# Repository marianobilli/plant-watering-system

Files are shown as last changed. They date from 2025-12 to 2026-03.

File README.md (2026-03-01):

# DIY Plant Watering System

> Automated single-plant watering on Arduino UNO R4 WiFi — dry-cycle logic, incremental dosing, 14-bit ADC, EEPROM logging, and a full LCD menu with calibration wizard.

[]()
[]()
[]()


---

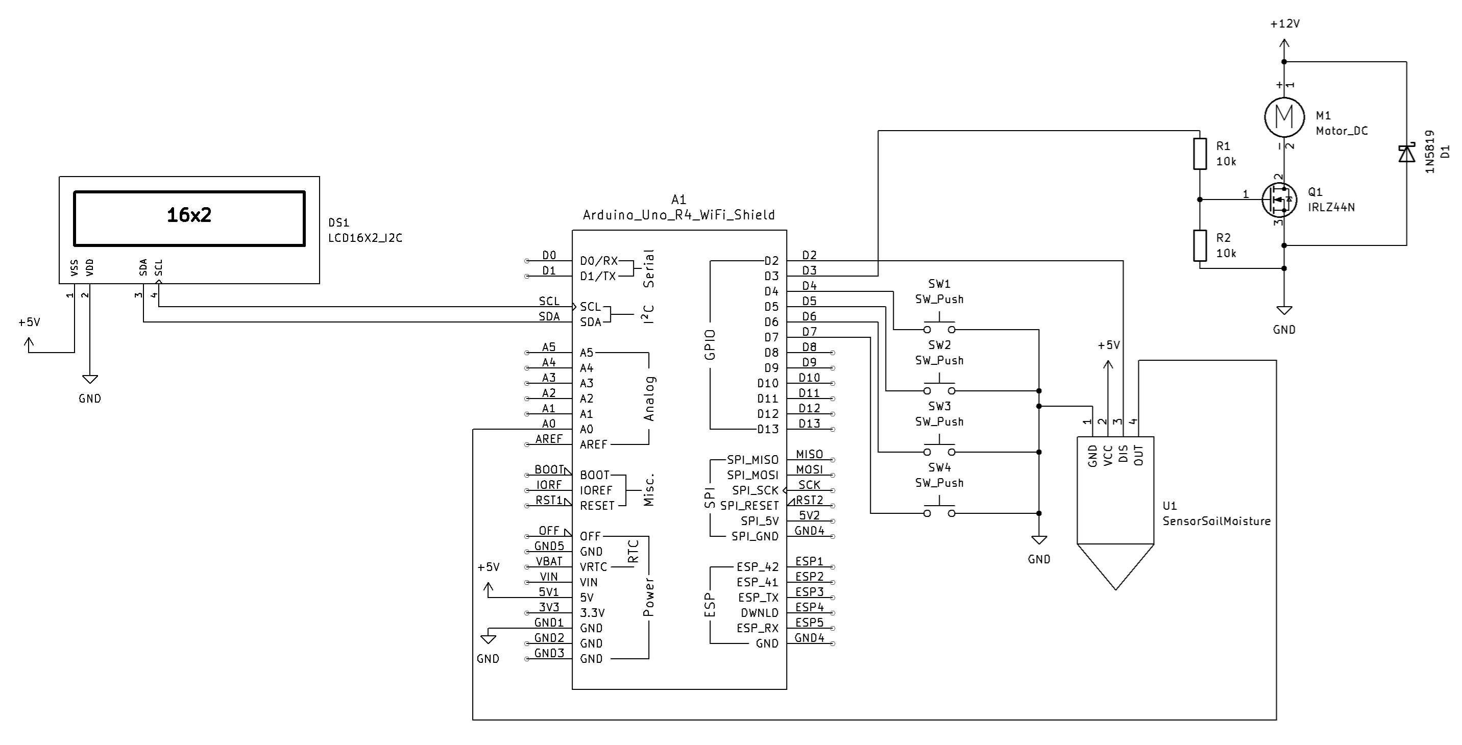
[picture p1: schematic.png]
Schematic


---

## How It Works

**Dry cycle** — Moisture is logged every 15 minutes. Auto-watering fires only after **two consecutive readings** below the minimum threshold (default 55%), avoiding false triggers from sensor noise.

**Incremental watering** — On the first trigger, the pump delivers an initial 50 mL dose, then waits 15 minutes for capillary absorption before re-reading. If moisture is still below the target (75%), additional 10 mL increments are delivered with 1-minute soak times between each. If moisture fails to rise after pumping, the system halts to prevent flooding.

---

## Key Design Decisions

| Decision | What | Why |
|---|---|---|
| Capacitive sensor | Cytron MCP6004-based | No electrolytic corrosion; lasts 1–2+ years vs weeks for resistive |
| DIS pin control | Sensor powered via D2 | Only energized during readings; extends sensor life, reduces parasitic current |
| 14-bit ADC | `analogReadResolution(14)` | 16 384 steps vs 1 024; far better moisture resolution |
| Median sampling | 10 samples, bubble sort | Rejects outliers; more stable than averaging alone |
| Peristaltic pump | 12V S-3Z type | Safe to run dry, precise dosing, no gravity siphoning |
| MOSFET switch | IRLZ44N logic-level | Silent, fast, no coil current; flyback diode (1N5819) on pump |
| Incremental watering | 50 mL initial + 10 mL steps | Prevents overwatering; allows soil absorption between doses |
| Soak times | 15 min initial / 1 min increment | Waits for capillary propagation before re-reading moisture |
| Dry-reading debounce | 2 consecutive low readings | Avoids watering on transient sensor noise |
| EEPROM circular log | 246 entries × 4 bytes | ~2.7 days of history at 15-min intervals; survives reboots |
| Backlight auto-sleep | 1 min timeout | Reduces LCD wear; wakes on any button press |

---

## Documentation

| File | Contents |
|---|---|
| [BOM.md](BOM.md) | Parts list with Allegro.pl / Botland.pl links and cost (~500 PLN) |
| [WATERING_LOGIC.md](WATERING_LOGIC.md) | Dry-cycle and incremental watering algorithm explained |
| [MENU_DESIGN.md](MENU_DESIGN.md) | 16×2 LCD menu structure, screen layouts, EEPROM map, state machine |
| [LESSONS_DEEP_RESEARCH.md](LESSONS_DEEP_RESEARCH.md) | Research findings from 50+ community projects |
| [watering/](watering/) | Firmware (v1.1), build guide, changelog |

---

## Repository Structure

```
plant-watering-system/
├── README.md
├── BOM.md
├── WATERING_LOGIC.md
├── MENU_DESIGN.md
├── LESSONS_DEEP_RESEARCH.md
└── watering/
    ├── README.md           # Build and upload guide
    ├── build.md            # Wiring, pin assignments, MOSFET circuit
    ├── BOM_WATERING.md     # Watering-system-specific BOM
    ├── CHANGELOG.md        # Firmware version history
    └── src/
        └── plant_watering/
            └── plant_watering.ino
```

---

## License

MIT

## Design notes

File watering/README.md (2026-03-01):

# Plant Watering System - Phase 2 (Auto-Watering Firmware)

Version 1.0 — First full auto-watering implementation combining reliable sensor reading with automatic watering logic.

## Overview

Phase 2 transforms the monitor-only firmware (Phase 1) into a **fully automatic plant watering system**. The firmware reads soil moisture via a 14-bit ADC sensor (with DIS pin control for power efficiency), and automatically activates a 12V peristaltic pump when soil moisture drops below a configurable threshold.

**Key improvements over POC:**
- ✅ **Correct 14-bit ADC handling** — includes `analogReadResolution(14)` to prevent ~16× calibration error
- ✅ **DIS pin sensor control** — extends sensor lifespan vs. VCC-cycling
- ✅ **Configurable median sampling** — robustness + flexibility (adjust sample count, delays)
- ✅ **EEPROM persistence** — all watering and sensor parameters saved across power cycles
- ✅ **Circular logging** — ~2.7 days of moisture history in 2KB EEPROM (~400 entries @ 15-min intervals)
- ✅ **Automatic failsafe** — stops watering if moisture doesn't increase (pump/sensor fault detection)

## Hardware Requirements

### Arduino & Sensor
- **1× Arduino UNO R4 WiFi** (or UNO R3 with WiFi shield if needed)
- **1× Capacitive Soil Moisture Sensor** with DIS pin (e.g., DF-Robot SEN0193 or similar)
- **1× 16x2 I2C LCD Display** (address 0x27 or 0x3F)
- **4× Pushbuttons** (UP/DOWN/SELECT/BACK navigation)

### Pump & Power Electronics
- **1× 12V Peristaltic Pump** (e.g., S-3Z model, ~1.67 mL/s flow rate)
- **1× IRLZ44N N-Channel Logic-Level MOSFET** (gate driver for pump)
- **1× 1N5819 Schottky Diode** (flyback protection on pump coil)
- **2× 10kΩ Resistors** (MOSFET gate current limit + pull-down)
- **1× 12V 2A Power Supply** (for pump + tube + connectors)
- **Dual USB + 12V Power** (Arduino from USB, pump from 12V) or single 12V supply with buck converter

## Pin Assignments

| Pin | Function | Purpose |
|-----|---|---|
| A0 | Soil Moisture Sensor ADC | Analog input (14-bit, 0-16383) |
| D2 | Sensor DIS Pin | Disable pin control (HIGH=sleep, LOW=active) |
| D3 | Pump MOSFET Gate | MOSFET control signal (HIGH=pump ON) |
| D4 | Button UP | Navigation up |
| D5 | Button DOWN | Navigation down |
| D6 | Button SELECT | Menu select / confirm |
| D7 | Button BACK | Menu back / cancel |
| SDA (A4) | LCD I2C Data | I2C communication |
| SCL (A5) | LCD I2C Clock | I2C communication |

## Firmware Features

### Operating Mode: Auto-Watering (Default)
- Continuous monitoring with configurable check intervals (1-24 hours)
- Dry cycle logic: only waters when soil moisture ≤ `minThreshold`
- Incremental watering: pumps configurable water amounts, waits for capillary absorption, checks moisture
- Automatic failsafe: stops if moisture doesn't increase (pump fault, sensor error, etc.)
- Soak time: waits N minutes between increments for moisture to propagate through soil

### Configuration (EEPROM-Persisted)
**Watering Parameters:**
- `targetHumidity` — Stop watering when moisture reaches this % (default: 75%)
- `minThreshold` — Start watering when moisture drops below this % (default: 55%)
- `waterAmountInitial` — Initial pump amount in mL (default: 50 mL)
- `waterAmountIncrement` — Each subsequent pump amount in mL (default: 10 mL)
- `checkInterval` — Hours between dry-cycle checks (default: 6 hours)
- `soakTime` — Minutes to wait after initial pump (default: 5 minutes)
- `soakTimeIncrement` — Minutes to wait between increments (default: 1 minute)
- `pumpRate` — mL/s calibrated from pump hardware (default: 1.67 mL/s)

**Sensor Parameters:**
- `sensorDry` — 14-bit ADC value in air (default: 11850, user-calibrated)
- `sensorWet` — 14-bit ADC value in water (default: 7700 @ 60cm depth)
- `sensorWarmup` — Sensor stabilization delay in ms (default: 1000ms)
- `numMeasurements` — Sample count for median (default: 10)
- `measurementDelay` — ms between samples (default: 100ms)

**Display:**
- `backlightTimeout` — LCD auto-sleep delay in minutes (default: 1 minute)

### Menu Structure
```
STATUS SCREEN
└─ [Select] → MAIN MENU
   ├─ Settings
   │  ├─ Target % (watering stop threshold)
   │  ├─ Min Threshold (watering start trigger)
   │  ├─ Water Amount (mL per increment)
   │  ├─ Check Interval (hours)
   │  ├─ Soak Time (minutes)
   │  ├─ Sensor Warmup (ms)
   │  ├─ Num Samples (count)
   │  └─ LCD Sleep (minutes)
   ├─ Calibrate
   │  ├─ Sensor (air → water or depth lookup)
   │  └─ Pump (measure actual mL output)
   ├─ Manual Water (trigger one cycle now)
   ├─ Download Log (Serial CSV dump)
   └─ Reset Defaults
```

### Data Logging
- **Circular EEPROM buffer:** ~400 entries × ~4 bytes = 2KB in EEPROM
- **Logging interval:** Configurable (default: 15 minutes)
- **Duration:** ~2.7 days of continuous monitoring at 15-min intervals before buffer wraps
- **CSV download:** Connect USB Serial Monitor @ 115200 baud, select "Download Log" → see CSV lines:
  ```
  1665.3,78,8567,0
  1680.5,79,8545,0
  ...
  ```
  (Time[hours], Moisture[%], Raw ADC, Flags)

## Building & Setup

See `build.md` for:
- Step-by-step wiring with corrected Arduino D2/D3 pins
- MOSFET circuit assembly (breadboard diagram)
- Sensor DIS pin vs. VCC-cycling explanation
- Power supply connections (dual USB+12V or single 12V)
- Safety checklist

## Calibration

### Sensor Calibration
1. Insert sensor in **air** (dry) — records ADC value (default: 11850)
2. Insert sensor in **water** at known depth (60cm recommended) — records ADC value (default: 7700)
3. Firmware maps [dry ADC → 0%, wet ADC → 100%]

See **monitor v1.5 sensor data** (from Phase 1): observed "healthy" moist soil reads 77–79% (ADC ~8567–8617)

### Pump Calibration
1. Run **Pump Calibration** wizard → pump runs for timed duration
2. Measure water collected in graduated cylinder (mL)
3. Enter mL — firmware calculates flow rate (mL/s)
4. Verifies pump is functional and rate is consistent with configuration

## Default Threshold Recommendation

Based on **monitor/data/data.csv** (Phase 1 real data):
- Healthy moist soil: 77–79% (ADC 8567–8617) over 8+ hours
- **Default:** `minThreshold = 55%` (triggers watering) → `targetHumidity = 75%` (stops when sufficiently moist)
- This provides earlier watering triggers for more frequent soil hydration, stopping at a lower moisture level

## Verification Steps

1. **Wiring test (no firmware):**
   - Connect MOSFET circuit, apply 12V
   - Briefly connect Arduino D3 to 5V → pump should spin

2. **Sensor test:**
   - Upload firmware
   - Open Serial Monitor @ 115200 baud
   - Verify ADC reads 10000–12000 in air (not 500–900, which indicates missing `analogReadResolution(14)`)

3. **Pump calibration:**
   - Run calibration wizard
   - Measure actual water output with graduated cylinder
   - Enter mL, firmware calculates rate

4. **Sensor calibration:**
   - Air (dry value) → water (wet value)
   - Verify % reads 0% in air, 100% in water

5. **Threshold test:**
   - Temporarily set `minThreshold = 70%`
   - Observe auto-watering triggers as expected
   - Reset to 40% after testing

6. **Log download:**
   - After a few watering cycles, open Serial Monitor
   - Select "Download Log" → observe CSV lines with moisture history

## Version History

See `CHANGELOG.md`

## Support

- **Wiring issues?** See `build.md` or `../WIRING_POC.md`
- **Sensor not reading?** Run Sensor Calibration wizard (Settings → Calibrate)
- **Pump not working?** Run Pump Calibration wizard to verify flow rate
- **Arduino won't upload?** Check USB cable, verify CH340 drivers (if using CH340 UART)

---

*Phase 2 v1.0 — Auto-Watering Firmware*
*Based on Phase 1 monitor v1.5 (sensor reading) + POC (watering logic)*
*Combines proven sensor code with enhanced watering reliability*

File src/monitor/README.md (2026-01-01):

# Soil Humidity Monitor - User Guide

**2-Week EEPROM Data Logger for Plant Moisture Analysis**

A simplified monitoring-only variant designed to help you understand your plant's natural watering cycles before implementing automatic irrigation. Logs 1,344 measurements over 14 days to Arduino UNO R4 WiFi's 8KB EEPROM.

---

## Quick Start (5-Minute Setup)

1. **Waterproof sensor** (2 coats clear nail polish, dry 24h)
2. **Wire components** per schematic (20 connections)
3. **Upload firmware** via Arduino IDE (30 seconds)
4. **Calibrate sensor** (Main Menu → Calibrate → air + water)
5. **Insert in soil** → Auto-logging begins!

**After 2 weeks:** Download CSV via Serial Monitor (115200 baud) → Analyze in Excel/Python

---

## Table of Contents

1. [Hardware Assembly](#hardware-assembly)
2. [Firmware Upload](#firmware-upload)
3. [First-Time Setup](#first-time-setup)
4. [Operating the System](#operating-the-system)
5. [CSV Download Instructions](#csv-download-instructions)
6. [Data Analysis Workflow](#data-analysis-workflow)
7. [Troubleshooting](#troubleshooting)
8. [Technical Specifications](#technical-specifications)

---

## Hardware Assembly

### Components Required

See [`BOM_MONITOR.md`](BOM_MONITOR.md) for complete parts list (~$42 USD).

**Core items:**
- Arduino UNO R4 WiFi
- Capacitive soil moisture sensor
- 16×2 I2C LCD display
- 4× tactile push buttons
- Breadboard + jumper wires
- USB-C cable (data + power)

### Wiring Diagram

**Pin Connections:**

| Component | Pin | Arduino Pin | Notes |
|---|-----|---|---|
| **Soil Sensor** | VCC | D2 | GPIO power control (critical!) |
| | AOUT | A0 | 14-bit ADC input |
| | GND | GND | Common ground |
| **16×2 LCD** | VCC | 5V | I2C module |
| | GND | GND | |
| | SDA | SDA (A4) | I2C data |
| | SCL | SCL (A5) | I2C clock |
| **Button UP** | Pin 1 | D4 | Internal pullup enabled |
| | Pin 2 | GND | Active LOW |
| **Button DOWN** | Pin 1 | D5 | Internal pullup |
| | Pin 2 | GND | |
| **Button SELECT** | Pin 1 | D6 | Internal pullup |
| | Pin 2 | GND | |
| **Button BACK** | Pin 1 | D7 | Internal pullup |
| | Pin 2 | GND | |
| **USB Cable** | USB-C | Arduino USB port | Power + Serial data |

**Complete schematic:** See [`soil_humidity_monitor.kicad_sch`](soil_humidity_monitor.kicad_sch)

### Assembly Steps

1. **Prepare Sensor (CRITICAL - do this first!):**
   ```
   1. Apply clear nail polish to sensor PCB (front + back)
   2. Avoid coating the metal probes themselves
   3. Let dry 30 minutes
   4. Apply second coat
   5. Let dry 24 hours before use
   ```
   **Why?** Waterproofing extends sensor life from 3-6 months to 1-2+ years.

2. **Connect LCD:**
   - 5V → LCD VCC
   - GND → LCD GND
   - SDA (A4) → LCD SDA
   - SCL (A5) → LCD SCL

3. **Connect Sensor:**
   - D2 → Sensor VCC (GPIO-powered!)
   - GND → Sensor GND
   - A0 → Sensor AOUT

4. **Connect Buttons:**
   - D4 → Button UP Pin 1, GND → Button UP Pin 2
   - D5 → Button DOWN Pin 1, GND → Button DOWN Pin 2
   - D6 → Button SELECT Pin 1, GND → Button SELECT Pin 2
   - D7 → Button BACK Pin 1, GND → Button BACK Pin 2

5. **Double-Check:**
   - [ ] No shorts between 5V and GND
   - [ ] Sensor powered from D2 (not 5V rail)
   - [ ] LCD I2C connections not swapped
   - [ ] All button pins connected to GND

---

## Firmware Upload

### Prerequisites

1. **Install Arduino IDE** (2.0 or newer)
   - Download: https://www.arduino.cc/en/software

2. **Install Board Support:**
   - Open Arduino IDE
   - Tools → Boards Manager → Search "Arduino UNO R4"
   - Install "Arduino UNO R4 Boards" by Arduino

3. **Install Libraries:**
   - Sketch → Include Library → Manage Libraries
   - Search and install:
     - **LiquidCrystal I2C** by Frank de Brabander (v1.1.2+)
   - Built-in libraries (no install needed): Wire, EEPROM

### Upload Steps

1. **Open Firmware:**
   - File → Open → Navigate to `soil_humidity_monitor.ino`

2. **Configure Board:**
   - Tools → Board → Arduino UNO R4 WiFi
   - Tools → Port → (select your Arduino's COM port)

3. **Upload:**
   - Click Upload button (→) or press Ctrl+U
   - Wait for "Done uploading" message (~30 seconds)

4. **Verify:**
   - LCD should display: "Plant Monitor" and "Initializing..."
   - Status screen should appear with "Moisture: --%" and "Log: 0/1344"

**Troubleshooting Upload Errors:**
- **Port not found:** Install CH340 USB drivers
- **Compilation error:** Check Arduino UNO R4 board support installed
- **Upload timeout:** Press reset button on Arduino, then upload again

---

## First-Time Setup

### 1. Initial Boot

LCD displays:
```
Plant Monitor
Initializing...
```

Then automatically shows **Status Screen**:
```
Moisture: --%
Log:0/1344
```

### 2. Sensor Calibration (REQUIRED)

**Why?** Each sensor has different ADC values for dry/wet conditions. Calibration ensures accurate 0-100% readings.

**Steps:**

1. **Enter Menu:**
   - Press SELECT button (LCD backlight turns on)
   - Display shows: "Main Menu" / "1. Settings"

2. **Navigate to Calibrate:**
   - Press DOWN button twice
   - Display shows: "Main Menu" / "2. Calibrate Sensor"
   - Press SELECT

3. **Dry Calibration:**
   - Display shows: "Hold sensor in AIR" / "Press SELECT"
   - Hold sensor in open air (not touching anything)
   - Wait 2 seconds for stable reading
   - Press SELECT
   - Display shows: "Dry value: XXXX" (e.g., 12400)

4. **Wet Calibration:**
   - Display shows: "Put sensor in WATER" / "Press SELECT"
   - Submerge sensor probes in glass of water (don't submerge entire PCB!)
   - Wait 2 seconds for water to saturate sensor
   - Press SELECT
   - Display shows: "Wet value: XXXX" (e.g., 6000)

5. **Confirmation:**
   - Display shows: "Calibration saved!" / "(values in EEPROM)"
   - Press BACK to return to Main Menu
   - Press BACK again to return to Status Screen

**Calibration values persist through power cycles** - you only need to do this once!

### 3. Adjust Log Interval (Optional)

Default: 15 minutes (optimal for 14-day storage)

**To change:**

1. Main Menu → 1. Settings
2. Press SELECT
3. Display shows: "Log Interval: 15 min"
4. Use UP/DOWN buttons to adjust (1-60 minutes)
5. Press SELECT to save
6. Press BACK to exit

**Storage duration based on interval:**

| Interval | Duration | Use Case |
|---|---|---|
| 10 min | 9.3 days | Fast data collection |
| 15 min | 14.0 days | **Default (optimal)** |
| 30 min | 28.0 days | Long-term trends |
| 60 min | 56.0 days | Extended monitoring |

---

## Operating the System

### Status Screen (Default View)

**What you see:**
```
Moisture: 75%
Log:456/1344
```

**Line 1:** Current soil moisture (0-100%)
- Updates every 2 seconds when backlight is on
- Shows "--%" before first calibration

**Line 2:** Logged entries / total capacity
- Example: "456/1344" = 456 readings stored, 1,344 max
- When full, oldest entries are automatically overwritten (circular buffer)

### Navigation Controls

| Button | Action |
|---|---|
| **UP** | Move up in menu / Increase value |
| **DOWN** | Move down in menu / Decrease value |
| **SELECT** | Enter menu / Confirm action |
| **BACK** | Exit menu / Cancel action |

**Backlight behavior:**
- Turns on when any button pressed
- Stays on for 1 minute
- Auto-sleeps to save power
- Data logging continues in background

### Menu Structure

```
STATUS SCREEN (default view)
│
SELECT → MAIN MENU
         ├── 1. Settings
         │   └── Log Interval (1-60 min)
         ├── 2. Calibrate Sensor
         │   ├── Hold in AIR → Press SELECT
         │   └── Put in WATER → Press SELECT
         ├── 3. Download Data
         │   ├── "Ready to download?" → SELECT to confirm
         │   ├── Progress bar (0-100%)
         │   └── "Download complete!"
         ├── 4. Clear Data
         │   └── "Clear all logs?" → SELECT to confirm
         ├── 5. System Info
         │   ├── "Entries: 456/1344"
         │   ├── "Days: 4.8/14.0"
         │   └── "Firmware: v1.0"
         └── 6. Reset to Defaults
             └── "Reset config?" → SELECT to confirm
```

### Automatic Logging

**How it works:**
- Every 15 minutes (or your configured interval), the system:
  1. Powers on sensor (D2 = HIGH)
  2. Waits 200ms for warmup
  3. Takes 20 ADC readings (averaged to reduce noise)
  4. Powers off sensor (D2 = LOW)
  5. Converts to 0-100% using calibration
  6. Writes 4-byte entry to EEPROM
  7. Updates entry counter

**No user action required** - logging happens automatically in background.

**Entry count updates:**
- Status screen shows current count
- When reaching 1,344 entries (capacity), oldest entries overwrite automatically
- Entry count freezes at 1,344 when buffer is full

---

## CSV Download Instructions

### Method 1: Arduino IDE Serial Monitor (Easiest)

1. **Connect Arduino** via USB cable to computer

2. **Open Serial Monitor:**
   - Arduino IDE → Tools → Serial Monitor
   - Set baud rate: **115200** (bottom-right dropdown)
   - Set line ending: "Newline" or "Both NL & CR"

3. **Start Download on Arduino:**
   - Press SELECT (enter Main Menu)
   - Navigate: DOWN → DOWN → "3. Download Data"
   - Press SELECT
   - Display shows: "Ready to download?" / "SELECT=Yes BACK=No"
   - Press SELECT to confirm

4. **Monitor Progress:**
   - Serial Monitor shows metadata header
   - CSV data rows stream (Entry, Timestamp, Moisture%, etc.)
   - LCD shows progress bar: "Downloading... [####----] 50%"
   - Takes ~30-60 seconds for 1,344 entries

5. **Save CSV File:**
   - When complete, Serial Monitor shows: "# End of data export"
   - Select all text in Serial Monitor (Ctrl+A)
   - Copy (Ctrl+C)
   - Paste into text editor
   - Save as `moisture_data.csv`

### Method 2: Command-Line Serial (Advanced)

**Linux/Mac:**
```bash
# Find Arduino port
ls /dev/tty.* | grep usb

# Start serial capture
screen /dev/tty.usbserial-XXXXXX 115200 > moisture_data.csv

# On Arduino: Main Menu → Download Data → SELECT
# Wait for download to complete
# Stop capture: Ctrl+A, then K, then Y
```

**Windows (PowerShell):**
```powershell
# Open serial port
$port = new-Object System.IO.Ports.SerialPort COM3,115200,None,8,One
$port.Open()

# On Arduino: Main Menu → Download Data → SELECT

# Read data to file
$data = $port.ReadLine()
$data | Out-File -FilePath moisture_data.csv -Append

# Close port when done
$port.Close()
```

### CSV Format

**Example output:**
```csv
# Soil Humidity Monitor Data Export
# Firmware Version: 1.0
# Total Entries: 1234
# Log Interval: 15 minutes
# Sensor Calibration: Dry=12400, Wet=6000
# Buffer Status: NOT_WRAPPED
#
Entry,Timestamp_Hours,Timestamp_Minutes,Moisture_%,Raw_ADC,Flags
1,0.00,0,45,8500,0x00
2,0.25,15,46,8450,0x00
3,0.50,30,47,8400,0x00
...
1234,308.25,18495,52,7800,0x00
```

**Columns:**
- **Entry:** Sequential number (1-1344)
- **Timestamp_Hours:** Hours since monitoring started
- **Timestamp_Minutes:** Total minutes since start
- **Moisture_%:** Calibrated moisture (0-100%)
- **Raw_ADC:** Raw 14-bit ADC value (0-16383)
- **Flags:** Status bits (0x00 = normal, 0x01 = sensor error)

---

## Data Analysis Workflow

### Step 1: Import CSV to Excel

1. Open Excel
2. Data → From Text/CSV
3. Select `moisture_data.csv`
4. Delimiter: Comma
5. Click Load

**Skip comment lines** (lines starting with `#`) or delete them manually.

### Step 2: Create Charts

**Time-Series Plot:**
- X-axis: `Timestamp_Hours` or `Timestamp_Minutes`
- Y-axis: `Moisture_%`
- Chart type: Scatter with smooth lines

**What to look for:**
- **Dry-down rate:** How fast moisture drops naturally
- **Watering events:** Sharp increases (if manually watered)
- **Stabilization level:** Where moisture settles after watering
- **Daily patterns:** Does moisture change with temperature/sunlight?

### Step 3: Calculate Key Metrics

**Natural Dry-Down Rate:**
```
Rate = (Moisture_start - Moisture_end) / Time_hours
Example: (80% - 30%) / 120 hours = 0.42% per hour
```

**Optimal Watering Threshold:**
- Find moisture level where plant shows stress (wilting)
- Water before reaching this point
- Typical range: 10-30% depending on plant species

**Moisture Propagation Time:**
- How long after watering does sensor see moisture increase?
- Typical: 5-15 minutes (depends on soil type, water amount)

### Step 4: Configure Automatic Watering

Use insights to configure POC automatic watering system:

1. **Set Min Threshold:** 5-10% above stress point
   - Example: Plant wilts at 15% → Set `minThreshold = 20%`

2. **Set Target Humidity:** Peak moisture after manual watering
   - Example: Manual watering reaches 75% → Set `targetHumidity = 75%`

3. **Set Soak Time:** Moisture propagation time + buffer
   - Example: Sensor updates in 8 minutes → Set `soakTime = 10 minutes`

4. **Set Check Interval:** 2-3× natural dry-down period
   - Example: Dries from 80% → 30% in 5 days → Set `checkInterval = 12 hours`

**See POC `plant_watering_poc.ino` for automatic watering implementation.**

### Example Analysis (Python)

```python
import pandas as pd
import matplotlib.pyplot as plt

# Load CSV
df = pd.read_csv('moisture_data.csv', comment='#')

# Plot time series
plt.figure(figsize=(12, 6))
plt.plot(df['Timestamp_Hours'], df['Moisture_%'], linewidth=1)
plt.xlabel('Time (hours)')
plt.ylabel('Soil Moisture (%)')
plt.title('2-Week Soil Moisture Monitoring')
plt.grid(True, alpha=0.3)
plt.tight_layout()
plt.savefig('moisture_trend.png', dpi=300)
plt.show()

# Calculate dry-down rate (linear regression)
from scipy.stats import linregress
slope, intercept, r_value, p_value, std_err = linregress(
    df['Timestamp_Hours'], df['Moisture_%']
)
print(f"Dry-down rate: {slope:.3f}% per hour")
print(f"R²: {r_value**2:.3f}")

# Find minimum moisture
min_moisture = df['Moisture_%'].min()
min_timestamp = df.loc[df['Moisture_%'].idxmin(), 'Timestamp_Hours']
print(f"Minimum moisture: {min_moisture}% at {min_timestamp:.1f} hours")
```

---

## Troubleshooting

### Sensor Issues

**Problem:** Moisture reads 0% or 100% constantly
- **Cause:** Sensor not calibrated
- **Fix:** Main Menu → Calibrate Sensor → Follow wizard (air + water)

**Problem:** Moisture fluctuates wildly (e.g., 20% → 80% → 30%)
- **Cause:** Poor electrical contact or sensor corrosion
- **Fix:**
  1. Check sensor wiring (AOUT to A0)
  2. Clean sensor probes with rubbing alcohol
  3. Re-waterproof if coating damaged
  4. Replace sensor if corroded

**Problem:** Moisture doesn't change when watering plant
- **Cause:** Sensor positioned in air pocket or outside water flow path
- **Fix:** Reposition sensor closer to roots, ensure soil contact

### EEPROM / Logging Issues

**Problem:** Entry count stuck at 0
- **Cause:** Logging interval expired but not saving entries
- **Fix:**
  1. Check System Info → verify interval not set to 0
  2. Reset to defaults: Main Menu → Reset to Defaults
  3. Recalibrate sensor

**Problem:** CSV download shows garbage data
- **Cause:** EEPROM corruption (rare) or wrong baud rate
- **Fix:**
  1. Verify Serial Monitor baud = **115200**
  2. Clear data: Main Menu → Clear Data
  3. Re-upload firmware if persists

**Problem:** "Buffer wrapped" but fewer than 1,344 entries
- **Cause:** Write pointer advanced incorrectly (firmware bug)
- **Fix:** Clear data and restart monitoring session

### LCD Display Issues

**Problem:** LCD shows nothing (blank screen)
- **Cause:** I2C address mismatch or wiring error
- **Fix:**
  1. Check LCD power (5V + GND)
  2. Verify SDA/SCL not swapped
  3. Try alternate I2C address: Change line 36 in `.ino`:
     ```cpp
     LiquidCrystal_I2C lcd(0x3F, 16, 2);  // Try 0x3F instead of 0x27
     ```
  4. Run I2C scanner sketch to detect address

**Problem:** LCD shows garbled characters
- **Cause:** Loose I2C connection or voltage issue
- **Fix:**
  1. Re-seat I2C jumper wires
  2. Verify 5V power (not 3.3V)
  3. Check common ground connection

**Problem:** Backlight stays on forever
- **Cause:** Expected behavior if buttons pressed within 1-minute window
- **Fix:** Wait 1 minute without pressing buttons → auto-sleeps

### Button Issues

**Problem:** Buttons don't respond
- **Cause:** Wiring error or wrong internal pullup configuration
- **Fix:**
  1. Verify button pin 1 to Arduino, pin 2 to GND
  2. Check firmware lines 180-183 (internal pullups enabled)
  3. Test with multimeter: button pressed = LOW (0V)

**Problem:** Single button press registers multiple times
- **Cause:** Electrical noise or debounce timing too short
- **Fix:** Firmware handles debouncing (50ms delay) - if persists, add 0.1µF capacitor across button pins

### CSV Download Issues

**Problem:** Serial Monitor shows no output
- **Cause:** Wrong baud rate or Arduino not connected
- **Fix:**
  1. Set Serial Monitor baud = **115200** (bottom-right dropdown)
  2. Verify USB cable is data cable (not charge-only)
  3. Check Arduino IDE → Tools → Port shows Arduino

**Problem:** Download hangs at X%
- **Cause:** Serial buffer overflow (rare on UNO R4)
- **Fix:**
  1. Close other serial programs using same port
  2. Try slower download (increase delay in firmware line 740)
  3. Use command-line serial capture instead of Arduino IDE

---

## Technical Specifications

### System Specifications

| Parameter | Value | Notes |
|---|---|---|
| **Storage Capacity** | 1,344 entries | 5,376 bytes EEPROM |
| **Storage Duration** | 14 days @ 15-min | User-adjustable 1-60 min |
| **Entry Size** | 4 bytes | Moisture%, ADC (2B), flags |
| **Configuration Size** | 32 bytes | Calibration, settings, pointers |
| **Unused EEPROM** | 2,784 bytes | Reserved for future features |
| **Buffer Type** | Circular | Auto-overwrites oldest entries |
| **ADC Resolution** | 14-bit (0-16383) | Arduino UNO R4 WiFi |
| **Sensor Power Duty Cycle** | 0.02% | Extends sensor life 4-8× |
| **Display Update Rate** | 2 seconds | When backlight active |
| **Backlight Timeout** | 1 minute | Auto-sleep to save power |
| **CSV Download Time** | 30-60 seconds | For 1,344 entries @ 115200 baud |

### EEPROM Endurance

- **Write Cycles:** 100,000 per address (Arduino UNO R4 WiFi spec)
- **Writes Per Day:** 96 entries (@ 15-min intervals)
- **Lifespan:** ~2,850 days (~7.8 years) per address rotation
- **Circular Buffer:** Each address written once every 14 days
- **Effective Lifespan:** 39,600 years (not a concern)

**Configuration header** (32 bytes) written only when user changes settings (~5 times over lifetime).

### Power Consumption

| Mode | Current | Notes |
|---|---|---|
| Active (logging) | ~40 mA | Sensor powered, LCD on |
| Idle (backlight off) | ~25 mA | Sensor off, LCD on |
| Sleep (future) | ~10 mA | Deep sleep between logs |

**USB-powered:** No external power supply needed (unlike POC variant with pump).

### Sensor Specifications

| Parameter | Typical Value | Range |
|---|---|---|
| Dry ADC (air) | 12,400 | 10,000-14,000 |
| Wet ADC (water) | 6,000 | 4,000-8,000 |
| ADC Range | 14-bit | 0-16,383 |
| Warmup Time | 200 ms | Before reading |
| Reading Time | 200 ms | 20 samples × 10ms |
| Power-On Duration | 400 ms total | Per 15-min cycle |
| Lifespan (continuous) | 3-6 months | Without GPIO power control |
| Lifespan (GPIO-powered) | 1-2 years | With 15-min duty cycle + waterproofing |

---

## Maintenance & Cleaning

### Regular Maintenance (Weekly)

- **Visual check:** Verify LCD displays current moisture
- **Entry count:** Check status screen, ensure logging continues
- **Sensor position:** Verify sensor hasn't shifted out of soil

### After Each Session (2-4 weeks)

1. **Download data** (backup before clearing)
2. **Clear EEPROM:** Main Menu → Clear Data
3. **Clean sensor:**
   - Remove from soil
   - Rinse with water
   - Wipe with soft cloth
   - Check waterproofing (re-coat if damaged)
4. **Restart monitoring** (or switch to POC automatic watering)

### Long-Term Storage

- **Remove sensor from soil** (prevents corrosion)
- **Disconnect USB power**
- **Store in dry location**
- **Configuration persists** - no need to recalibrate after storage

---

## Next Steps

### After 2-Week Monitoring

You now have quantitative data to configure automatic watering!

**Recommended workflow:**

1. **Analyze CSV data** (see Data Analysis Workflow above)
2. **Calculate optimal thresholds** from moisture trends
3. **Assemble POC automatic watering variant:**
   - Add 12V peristaltic pump + MOSFET circuit
   - See `../poc/plant_watering_poc.ino`
4. **Configure watering parameters** based on monitoring data:
   - `minThreshold` (when to start watering)
   - `targetHumidity` (when to stop watering)
   - `soakTime` (moisture propagation delay)
   - `checkInterval` (how often to check moisture)
5. **Test automatic watering** in Monitor mode first (dry run)
6. **Enable Watering mode** when confident in configuration

**See `../poc/README.md` for POC automatic watering setup guide.**

---

## Support & Feedback

- **Issues:** Report bugs at project repository
- **Firmware version:** Check Main Menu → System Info
- **Schematic:** See `soil_humidity_monitor.kicad_sch`
- **BOM:** See `BOM_MONITOR.md`
- **Project overview:** See `../../CLAUDE.md`

**Current firmware version:** v1.0 (stable)

---

## Changelog

### v1.0 (2024-12-31)
- Initial release
- 1,344-entry circular buffer
- 15-minute default interval
- CSV download via Serial
- Sensor calibration wizard
- Settings menu (log interval adjustment)
- Backlight auto-sleep (1 minute)
- System info screen
- Clear data function
- Reset to defaults function

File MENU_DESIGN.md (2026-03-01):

# LCD Menu System Design — v1.1

Hardware: Arduino UNO R4 WiFi · 16×2 I2C LCD · 4 buttons

## Button Layout

| Button | Pin | Function |
|---|-----|---|
| UP | D4 | Navigate up / increase value |
| DOWN | D5 | Navigate down / decrease value |
| SELECT | D6 | Confirm / enter submenu / toggle |
| BACK | D7 | Cancel / return to previous screen |

Debounce delay: **200 ms**

---

## Default Configuration

| Parameter | Default | Unit | Notes |
|---|---|---|---|
| Target humidity | 75 | % | Stop watering at this moisture |
| Min threshold | 55 | % | Start watering below this |
| Initial water amount | 50 | mL | First pump dose |
| Increment water amount | 10 | mL | Subsequent doses |
| Check interval | 6 | hours | Dry cycle check frequency |
| Soak time (initial) | 15 | min | Wait after first pump |
| Soak time (increment) | 1 | min | Wait between increments |
| Sensor dry ADC | 11850 | — | 14-bit ADC value in air |
| Sensor wet ADC | 7700 | — | 14-bit ADC value in water @ 60cm |
| Pump rate | 1.67 | mL/s | Typical S-3Z peristaltic pump |
| Backlight timeout | 1 | min | LCD auto-sleep |
| Sensor warmup | 1000 | ms | Stabilisation delay after power-on |
| Num samples | 10 | — | Median filter sample count |
| Sample delay | 100 | ms | Delay between samples |
| Log interval | 15 | min | EEPROM circular buffer write rate |
| Watering enabled | ON | — | Auto-watering active by default |

---

## Menu Structure

```
STATUS_SCREEN (default idle)
│
└── [any button] → MAIN_MENU (6 items, scroll one at a time)
    ├── 1.Settings     → SETTINGS_MENU (12 items)
    │   ├── Target %          → SETTING_TARGET
    │   ├── Min Thresh %      → SETTING_MIN
    │   ├── Init Water mL     → SETTING_AMOUNT_INITIAL
    │   ├── Incr Water mL     → SETTING_AMOUNT_INCREMENT
    │   ├── Check hrs         → SETTING_INTERVAL
    │   ├── Soak min          → SETTING_SOAK_TIME
    │   ├── Soak Incr min     → SETTING_SOAK_TIME_INCREMENT
    │   ├── Log min           → SETTING_LOG_INTERVAL
    │   ├── Warmup ms         → SETTING_SENSOR_WARMUP
    │   ├── Samples           → SETTING_NUM_MEASUREMENTS
    │   ├── Delay ms          → SETTING_MEASUREMENT_DELAY
    │   └── Backlight         → SETTING_BACKLIGHT_TIMEOUT
    │
    ├── 2.Calibrate    → CALIBRATE_MENU
    │   ├── 1.Sensor   → CAL_SENSOR_MENU
    │   │   ├── 1.Measure Air   → CAL_SENSOR_AIR   → CAL_SENSOR_DONE
    │   │   └── 2.Measure Water → CAL_SENSOR_WATER  → CAL_SENSOR_DONE
    │   └── 2.Pump     → CAL_PUMP_START → CAL_PUMP_RUNNING
    │                               [BACK stops pump] → CAL_PUMP_ENTER_ML
    │                                                 → CAL_PUMP_DONE
    │
    ├── 3.Manual Water → MANUAL_WATER_CONFIRM → waterPlant() → STATUS_SCREEN
    ├── 4.Download Log → DOWNLOAD_CONFIRM → downloadLog() → STATUS_SCREEN
    ├── 5.Reset        → RESET_CONFIRM → saveDefaults() → STATUS_SCREEN
    └── 6.Watering: ON/OFF  [SELECT toggles, saves immediately]
```

---

## Screen Layout Examples (16×2 LCD)

### Status Screen (idle)

```
┌────────────────┐
│Moisture: 68%   │
│OK              │
└────────────────┘
```

Line 2 variants:

| Condition | Line 2 |
|---|---|
| Watering disabled | `Watering: OFF  ` |
| Moisture ≤ minThreshold, 2nd dry reading | `Dry! Watering  ` |
| Moisture ≤ minThreshold, 1st dry reading | `Need water! ` |
| Moisture > minThreshold | `OK ` |

### Main Menu

Shows one item at a time. UP/DOWN scrolls; SELECT enters.

```
┌────────────────┐
│1.Settings      │
│Press SELECT    │
└────────────────┘
```

Item 6 (Watering toggle):

```
┌────────────────┐
│6.Watering: ON  │
│Press SELECT    │
└────────────────┘
```

### Settings Menu

```
┌────────────────┐
│Target %        │
│Press SELECT    │
└────────────────┘
```

### Setting Adjustment Screen

```
┌────────────────┐
│Target:         │
│75% (UP/DN)     │
└────────────────┘
```

```
┌────────────────┐
│Init:           │
│50mL (UP/DN)    │
└────────────────┘
```

```
┌────────────────┐
│Soak:           │
│15min (UP/DN)   │
└────────────────┘
```

BACK saves and returns to settings list.

### Calibrate Menu

```
┌────────────────┐
│1.Sensor        │
│Press SELECT    │
└────────────────┘
```

### Sensor Calibration — Measure Air

```
┌────────────────┐
│1.Measure Air   │
│Press SELECT    │
└────────────────┘
```

During measurement:

```
┌────────────────┐
│Air: 11850      │
│SELECT to save  │
└────────────────┘
```

### Sensor Calibration — Measure Water

```
┌────────────────┐
│2.Measure Water │
│Press SELECT    │
└────────────────┘
```

```
┌────────────────┐
│Water: 7700     │
│SELECT to save  │
└────────────────┘
```

After saving either:

```
┌────────────────┐
│Cal saved!      │
│Dry=11850 Wet=7700│
└────────────────┘
```

### Pump Calibration

```
┌────────────────┐
│Pump Calibration│
│SELECT to run   │
└────────────────┘
```

Running (press BACK to stop):

```
┌────────────────┐
│Pump running... │
│5s (BACK stop)  │
└────────────────┘
```

Enter collected mL:

```
┌────────────────┐
│Enter mL:15     │
│UP/DN then SELECT│
└────────────────┘
```

Done:

```
┌────────────────┐
│Rate: 1.67mL/s  │
│Press BACK      │
└────────────────┘
```

### Manual Watering

```
┌────────────────┐
│Manual Watering?│
│SELECT=yes BACK=no│
└────────────────┘
```

### Download Log

```
┌────────────────┐
│Download Log    │
│SELECT=yes BACK=no│
└────────────────┘
```

SELECT outputs CSV to Serial at 115200 baud (timestamp index, moisture %, raw ADC, flags).

### Reset to Defaults

```
┌────────────────┐
│Reset to        │
│Defaults? SEL/BCK│
└────────────────┘
```

---

## Navigation State Machine

```cpp
enum MenuState {
    STATUS_SCREEN,
    MAIN_MENU,
    SETTINGS_MENU,
    SETTING_TARGET,
    SETTING_MIN,
    SETTING_AMOUNT_INITIAL,
    SETTING_AMOUNT_INCREMENT,
    SETTING_INTERVAL,
    SETTING_SOAK_TIME,
    SETTING_SOAK_TIME_INCREMENT,
    SETTING_LOG_INTERVAL,
    SETTING_SENSOR_WARMUP,
    SETTING_NUM_MEASUREMENTS,
    SETTING_MEASUREMENT_DELAY,
    SETTING_BACKLIGHT_TIMEOUT,
    CALIBRATE_MENU,
    CAL_SENSOR_MENU,
    CAL_SENSOR_AIR,
    CAL_SENSOR_WATER,
    CAL_SENSOR_DONE,
    CAL_PUMP_START,
    CAL_PUMP_RUNNING,
    CAL_PUMP_ENTER_ML,
    CAL_PUMP_DONE,
    MANUAL_WATER_CONFIRM,
    MANUAL_WATER_RUNNING,
    DOWNLOAD_MENU,
    DOWNLOAD_CONFIRM,
    DOWNLOAD_PROGRESS,
    RESET_CONFIRM
};
```

### Button Actions by State

| State | UP | DOWN | SELECT | BACK |
|---|----|---|---|---|
| STATUS_SCREEN | → MAIN_MENU | → MAIN_MENU | → MAIN_MENU | — |
| MAIN_MENU | prev item | next item | enter item | → STATUS_SCREEN |
| SETTINGS_MENU | prev item | next item | enter setting | → MAIN_MENU |
| SETTING_* | increase | decrease | — | save → SETTINGS_MENU |
| CALIBRATE_MENU | prev item | next item | enter | → MAIN_MENU |
| CAL_SENSOR_MENU | prev item | next item | enter step | → CALIBRATE_MENU |
| CAL_SENSOR_AIR/WATER | — | — | save → CAL_SENSOR_DONE | → CAL_SENSOR_MENU |
| CAL_SENSOR_DONE | — | — | → CALIBRATE_MENU | → CAL_SENSOR_MENU |
| CAL_PUMP_START | — | — | → CAL_PUMP_RUNNING | → CALIBRATE_MENU |
| CAL_PUMP_RUNNING | — | — | — | stop pump → CAL_PUMP_ENTER_ML |
| CAL_PUMP_ENTER_ML | increase | decrease | calc rate → CAL_PUMP_DONE | → CAL_PUMP_START |
| CAL_PUMP_DONE | — | — | — | → CALIBRATE_MENU |
| MANUAL_WATER_CONFIRM | — | — | waterPlant() → STATUS | → STATUS |
| DOWNLOAD_CONFIRM | — | — | downloadLog() → STATUS | → STATUS |
| RESET_CONFIRM | — | — | saveDefaults() → STATUS | → STATUS |

---

## EEPROM Memory Map

Header: **40 bytes** (addresses 0–39). Data: addresses 40–1023 (circular buffer).

```
Addr  Size  Field
   0     2  Magic number (0xA5C3)
   2     2  Firmware version
   4     1  Target humidity (0–100)
   5     1  Min threshold (0–100)
   6     2  Initial water amount (mL × 10)
   8     2  Increment water amount (mL × 10)
  10     1  Check interval (hours)
  11     1  Soak time after initial pump (minutes)
  12     1  Soak time between increments (minutes)
  13     2  Sensor dry ADC (14-bit)
  15     2  Sensor wet ADC (14-bit)
  17     4  Pump rate (float, mL/s)
  21     2  Backlight timeout (minutes)
  23     2  Sensor warmup (milliseconds)
  25     1  Number of measurements (5–50)
  26     2  Measurement delay (milliseconds)
  28     2  Log interval (minutes)
  30     4  Circular buffer write pointer
  34     4  Total entries written
  38     1  Watering enabled (0=off, 1=on)
  39     1  (reserved / alignment)
  40  984  Log data: 246 entries × 4 bytes each
            Entry layout: moisture% (1B) | rawADC high (1B) | rawADC low (1B) | flags (1B)
```

Log flags: `0x00` normal · `0x01` watering started · `0x02` watering complete

---

## Value Adjustment Steps

| Parameter | Step | Min | Max |
|---|---|-----|-----|
| Target / Min threshold | 1% | 0 | 100 |
| Initial / Increment water | 1 mL (10 in storage) | 1 mL | 500 mL |
| Check interval | 1 h | 1 | 24 |
| Soak time (both) | 1 min | 1 | 30 |
| Log interval | 1 min | 1 | 60 |
| Sensor warmup | 1 ms (display) | 100 | 2000 |
| Num samples | 1 | 5 | 50 |
| Measurement delay | 1 ms | 10 | 500 |
| Backlight timeout | 1 min | 1 | 60 |

---

## Timing

- Button debounce: **200 ms**
- Display update (status screen): every **2 s**
- Auto-watering check: every **logInterval** minutes (default 15 min)
- Watering triggers after **2 consecutive** below-threshold readings
- Backlight auto-sleep: after **backlightTimeout** minutes of inactivity (default 1 min)

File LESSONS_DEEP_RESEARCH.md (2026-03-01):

# DIY Plant Watering Systems: Hard-Won Lessons from the Maker Community

After analyzing dozens of projects across Reddit, Hackster.io, Instructables, GitHub, and maker blogs, a clear pattern emerges: the difference between systems that run for years versus those that fail within months comes down to a handful of critical decisions that most tutorials skip entirely.

## Sensor selection determines project lifespan

- **Resistive sensors (YL-69, HL-69, FC-28) should be avoided entirely.** They pass current through soil, causing electrolytic corrosion that destroys the electrodes within weeks. Multiple makers reported sensors dissolving, with unknown metals leaching into soil.
- **Capacitive sensors (v1.2) are better but require careful handling.** Many sensors ship with NE555 chips instead of TLC555; NE555 requires minimum 4.5V, making it incompatible with ESP32's 3.3V GPIO. Some batches also have a missing solder bridge between R4 and ground.
- **Waterproofing is mandatory.** The electronics portion is not waterproof. Seal with two coats of clear nail polish, PlastiDip, or adhesive-lined heat-shrink (3:1 ratio) before deployment.

| Sensor Type | Typical Lifespan | Key Issue |
|---|---|---|
| Resistive (YL-69) | 2 weeks–3 months | Electrolytic corrosion |
| Capacitive (cheap) | 3–6 months | Water intrusion, chip defects |
| Capacitive (sealed) | 1–3 years | Requires proper waterproofing |
| DIYables/DFRobot branded | 2+ years | Higher quality control |

## Power sensors from GPIO pins to extend life dramatically

- Power the sensor from a GPIO pin and take readings only when needed. This extends sensor life, reduces deep-sleep current from milliamps to microamps, and prevents parasitic power draw through ADC inputs.
- Allow 200–400 ms warmup after powering on before reading. One well-documented project achieved 15 µA deep-sleep current and 251 days runtime on a 200 mAh battery using this approach.

## ESP32 ADC and WiFi have critical constraints

- **ADC2 pins cannot be used while WiFi is active.** Use only ADC1 pins (GPIO32, 33, 34, 35, 36, 39) for sensors when WiFi is enabled.
- **ADC readings are noisy.** Every successful project implements averaging or median filtering (10–64 samples typical).
- Calibrate in your actual soil. Typical capacitive sensor ranges: ~1500 (wet) to ~3100 (dry) on ESP32, but this varies significantly by batch and soil type.

## WiFi reconnection requires explicit code

- The ESP32 does not automatically reconnect to WiFi after losing signal or after router reboots. Without explicit reconnection logic, the system stays disconnected until manually reset.
- Additional stability fixes: set router to 20 MHz channel width, keep signal better than −70 dBm, use static IP instead of DHCP, and implement fallback AP mode. DHCP lease expiration is a common cause of random disconnects.

## Pump selection affects reliability and controllability

- **Never run submersible pumps dry**—this destroys plastic gears within minutes. Always implement water-level sensing with automatic pump cutoff.
- **Peristaltic pumps are superior for most DIY applications.** They can run dry without damage, provide precise dosing, prevent gravity siphoning when stopped, and don't contact the liquid. Tradeoff: lower flow rates and tubing wear requiring replacement every 6–12 months.
- **Flyback diodes are mandatory** on all pump and solenoid connections. Use a 1N4007 (or 1N5819 for lower drop) across motor terminals, cathode to positive.

## Power management for battery systems

- Deep sleep is essential for battery operation. Known ESP32 bug: after a random number of wake cycles, the device never wakes again. Fix: add a 500 ms delay after waking before reading RTC memory.
- Real-world deep-sleep current varies dramatically by board: standard DOIT ESP32 draws ~19 mA in deep sleep (board design issue); Firebeetle ESP32 achieves 0.01 mA. Using ESP-NOW instead of WiFi can extend runtime 6.4× on the same battery.

## Mechanical and tubing lessons from extended operation

- **Keep water reservoir below plant level.** If above, siphoning continues after the pump stops, draining the entire tank.
- **Closed-end hose with drilled holes beats Y-splitters.** Splitters consistently fail to distribute water evenly—some plants flood, others go dry.
- **Use opaque tubing.** Transparent tubing grows algae rapidly in light. Narrow tubing (1/4") clogs faster with mineral buildup than wider tubing.

## Software patterns that prevent failures

- **Implement failsafe logic.** If moisture doesn't increase after pumping, stop pumping immediately to prevent flooding.
- **Use state machines instead of `delay()`.** Blocking delays prevent sensor reads, WiFi maintenance, and watchdog feeding.
- **Add hardware watchdog timers.** Memory leaks and unexpected hangs happen—automatic reboot prevents permanent failure.

## Component recommendations based on community experience

| Component | Recommended | Avoid |
|---|---|---|
| Moisture Sensor | Capacitive with TLC555 chip, waterproofed | Resistive (YL-69, HL-69); Capacitive with NE555 |
| Pump | Peristaltic for precision; quality submersible with dry-run protection | Cheap unbranded submersibles |
| ESP32 Board | Firebeetle (low power) or ESP32-C3 | Boards with always-on LEDs/USB chips |
| Relay | 5V module with optocoupler; SSR for long-term | Direct GPIO switching; cheap modules without isolation |
| Power | Separate supplies for MCU and pumps | USB power for motors; 12V direct to Arduino Vin |
| Tubing | 5–6 mm ID opaque hose; silicone for peristaltic | Clear tubing outdoors; very narrow tubing throughout |

## Maintenance schedule that emerged from experience

**Weekly:** Check reservoir level, verify pump with manual test, review moisture readings for anomalies.

**Monthly:** Inspect tubing for algae/mineral buildup, verify sensor readings against manual soil check.

**Quarterly:** Inspect sensors for corrosion, recalibrate if readings have drifted, check electrical connections.

**Annually:** Replace tubing (including peristaltic pump tubing), deep clean reservoir, replace sensors showing drift, update firmware.

## Conclusion

The maker community's collective experience reveals that successful DIY plant watering depends less on sophisticated features than on getting fundamentals right. Three decisions prevent most failures: using properly waterproofed capacitive sensors powered intermittently from GPIO, implementing explicit WiFi reconnection logic, and adding dry-run protection for pumps. The projects that run for years share common traits—failsafe logic, averaged sensor readings, separate power supplies for motors, and planned maintenance intervals.

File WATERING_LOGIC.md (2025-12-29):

# Watering Logic - Detailed Explanation

## Overview

The system uses a **two-phase cycle** to water plants intelligently while allowing natural soil drying:

1. **Watering Phase** - Waters until upper limit reached
2. **Dry Cycle Phase** - Waits until lower limit reached before watering again

---

## Default Configuration (Per Plant Profile)

| Parameter | Default Value | Range | Description |
|---|---|---|---|
| **Upper Limit** (Target) | 80% | 0-100% | Stop watering when this moisture level is reached |
| **Lower Limit** (Minimum) | 10% | 0-100% | Start watering when moisture drops to this level |
| **Water Amount** | 50 mL | 1-999 mL | Amount to water per iteration |
| **Soak Time** | 5 minutes | 1-30 min | Wait time for capillarity after each watering |
| **Check Interval** | 6 hours | 1-24 hours | How often to check moisture during dry cycle |

**Note:** Dry cycle is always enabled - it's core to the watering logic and essential for plant health.

---

## Phase 1: Watering Phase

**Trigger:** Moisture drops to or below **Lower Limit** (10%)

**Process:**
1. **Water** the configured amount (50 mL default)
2. **Wait** for soak time (5 minutes default) to allow capillarity
3. **Re-measure** soil moisture
4. **Check** if moisture is below upper limit (80%)
   - If **YES** → Repeat steps 1-4
   - If **NO** (reached 80% or higher) → Enter Dry Cycle Phase

**Example:**
```
Initial moisture: 8% (below 10% minimum)
→ Water 50mL
→ Wait 5 minutes (capillarity)
→ Measure: 45%
→ Still below 80%, so continue...
→ Water 50mL
→ Wait 5 minutes
→ Measure: 82%
→ Reached target! Enter dry cycle
```

---

## Phase 2: Dry Cycle Phase

**Trigger:** Moisture reaches or exceeds **Upper Limit** (80%)

**Process:**
1. **Wait** for check interval (6 hours default)
2. **Measure** soil moisture
3. **Check** if moisture is at or below lower limit (10%)
   - If **NO** (still above 10%) → Continue waiting (repeat steps 1-3)
   - If **YES** (dropped to 10% or below) → Enter Watering Phase

**Purpose:**
- Prevents constant watering
- Allows natural soil drying cycle
- Healthier for plant roots (prevents root rot)
- Mimics natural rainfall patterns

**Example:**
```
After watering: 82%
→ Wait 6 hours
→ Measure: 65%
→ Still above 10%, stay in dry cycle
→ Wait 6 hours
→ Measure: 42%
→ Still above 10%, stay in dry cycle
→ Wait 6 hours
→ Measure: 9%
→ Below 10%! Start watering phase
```

---

## Failsafe Protection

The system includes safety checks to prevent damage:

### 1. Moisture Not Increasing
**Problem:** Sensor or pump failure
**Detection:** After watering, moisture didn't increase from previous reading
**Action:**
- Stop watering immediately
- Display error: "Water not absorbing - check sensor/pump"
- User must resolve issue before system continues

### 2. Maximum Iterations
**Problem:** System can't reach target (leak, wrong calibration, etc.)
**Detection:** Watered 10 times without reaching upper limit
**Action:**
- Stop watering to prevent flooding
- Log warning for user review

---

## Why Soak Time is Critical

**Without soak time:**
```
Water 50mL → Measure immediately → Sensor reads 15% (water hasn't spread)
→ System thinks soil is still dry
→ Water another 50mL → Measure → Still reads low
→ Keeps watering → FLOOD!
```

**With soak time (5 minutes):**
```
Water 50mL → Wait 5 minutes → Water spreads via capillary action
→ Measure → Sensor reads 45% (accurate)
→ Water 50mL → Wait 5 minutes
→ Measure → 82% (reached target, stop)
```

**Capillary action timing:**
- **Sandy soil** (fast drainage): 3-5 minutes
- **Loam** (medium drainage): 5-10 minutes
- **Clay** (slow drainage): 10-15 minutes
- **Default (potting mix)**: 5 minutes

---

## Per-Plant Profiles (Phase 2 - Future)

In the final 6-plant system, each plant will have independent configuration:

```
Plant 1 (Cactus):
  - Upper: 40%, Lower: 5%
  - Amount: 20mL, Soak: 3min
  - Check: 12 hours

Plant 2 (Fern):
  - Upper: 90%, Lower: 60%
  - Amount: 100mL, Soak: 7min
  - Check: 4 hours

Plant 3 (Tomato):
  - Upper: 80%, Lower: 20%
  - Amount: 150mL, Soak: 10min
  - Check: 6 hours
```

Each plant operates independently with its own cycle.

---

## Why Dry Cycle is Always Enabled

The dry cycle is **always ON** in this system - it's not optional. Here's why:

```
Watering phase: Water when moisture ≤ 10% until 80%
Dry cycle phase: Wait (no watering) until moisture ≤ 10%
Check interval: 6 hours
```

**Benefits:**
- **Prevents root rot:** Constant moisture kills roots through oxygen deprivation
- **Mimics nature:** Natural rainfall has wet/dry cycles
- **Stronger roots:** Dry periods encourage deeper root growth
- **Prevents fungal growth:** Wet soil breeds mold and fungus
- **Better oxygen exchange:** Dry periods allow soil to breathe

**Without dry cycle:**
- Soil stays constantly wet (60-80% moisture)
- High risk of root rot and plant death
- Fungal infections and pest problems
- Weak, shallow root systems

The configurable parameters (10% minimum, 80% maximum) allow customization for different plant species while maintaining the healthy wet/dry cycle.

---

## Configuration via LCD Menu (POC)

Navigate to: **Main Menu → Settings**

```
Settings Menu:
├── Target (Upper limit)     → 80% (default)
├── Min (Lower limit)        → 10% (default)
├── Amount (per watering)    → 50mL (default)
├── Check Interval           → 6h (default)
└── Soak Time                → 5min (default)
```

**Note:** Dry cycle is always ON and not shown in menu - it's a core part of the system.

**Adjustment:**
- Use **UP/DOWN** buttons to change value
- Press **SELECT** to save
- Press **BACK** to cancel

---

## Real-World Example Timeline

**Plant:** Tomato in 5L pot with potting mix
**Configuration:** Target 80%, Min 10%, 50mL per watering, 5min soak, 6h check

**Day 1:**
```
00:00 - Moisture: 8% → START WATERING PHASE
00:00 - Water 50mL
00:05 - Measure: 42%
00:05 - Water 50mL (still below 80%)
00:10 - Measure: 81% → ENTER DRY CYCLE
06:10 - Check: 72% (above 10%, continue dry cycle)
12:10 - Check: 61%
18:10 - Check: 48%
```

**Day 2:**
```
00:10 - Check: 35%
06:10 - Check: 22%
12:10 - Check: 9% → START WATERING PHASE
12:10 - Water 50mL
12:15 - Measure: 45%
12:15 - Water 50mL
12:20 - Measure: 83% → ENTER DRY CYCLE
```

---

## Summary

✅ **Watering Phase:** Water in 50mL increments with 5min soak until 80% reached
✅ **Dry Cycle Phase:** Check every 6 hours, water only when ≤10%
✅ **Failsafe:** Stop if moisture doesn't increase
✅ **Configurable:** All parameters adjustable per plant
✅ **Intelligent:** Mimics natural watering patterns for healthier plants

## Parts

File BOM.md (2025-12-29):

# Bill of Materials - POC (Phase 1)

**Note:** This POC uses the **Arduino UNO R4 WiFi** (already owned in GeeekPi kit) to start immediately without waiting for additional components. The final 6-plant system (Phase 2) will use ESP32 for lower cost and power consumption.

## Components Purchased / Already Owned

### Main POC Hardware

| Qty | Component | Specifications | Price (PLN) | Status | Link | Notes |
|-----|---|---|---|---|---|---|
| 1 | ✅ **Arduino UNO R4 WiFi** | Renesas RA4M1, WiFi, 5V logic | Included in kit (~408 PLN) | ✅ Owned | [GeeekPi Kit](https://www.amazon.com/GeeekPi-Arduino-Development-Starter-Tutorial/dp/B0CSLF61WF) | **POC Microcontroller** |
| 1 | ✅ Peristaltic Pump | 12V dosing pump | ~25 PLN | ✅ Owned | [Allegro](https://allegro.pl/oferta/pompa-perystaltyczna-dozujaca-12v-wyprzedaz-12598165922) | Self-priming, can run dry |
| 5 | ✅ IRLZ44N MOSFET | N-channel logic-level, 55V, 47A, TO-220 | ~8 PLN (5pcs) | ✅ Owned | [Botland](https://botland.com.pl/n-mosfet/1950-n-mosfet-irlz44n-55v47a-tht-5szt-5904422373276.html) | Logic-level, works with 5V |
| 10 | ✅ 1N5819 Schottky Diode | 40V, 1A | ~3 PLN (10pcs) | ✅ Owned | [Botland](https://botland.com.pl/diody-schottky/306-dioda-schottky-1n5819-1a-40v-10szt-5903351244480.html) | Flyback protection |
| 1 | ✅ Cytron Soil Moisture Sensor | MCP6004 op-amp, 1.8-6V, analog | ~22 PLN | ✅ Owned | [Allegro](https://allegro.pl/oferta/maker-soil-moisture-sensor-pojemnosciowy-czujnik-wilgotnosci-gleby-18074990169) | **MUST waterproof!** |
| 1 | ✅ Resistor Kit | 600pcs THT 0.25W 1/4W, 20×30 values | ~17 PLN | ✅ Owned | [Allegro](https://allegro.pl/oferta/zestaw-600-rezystorow-tht-opornik-0-25w-1-4w-1-20x30-roznych-wartosci-17379583399) | Includes 10kΩ for MOSFET gate |
| 1 | ✅ LCD Display 1602 | 16x2 I2C LCD | Included in kit | ✅ Owned | From GeeekPi kit | **16×2 size** |
| 4+ | ✅ Push Buttons | Tactile switches | Included in kit | ✅ Owned | From GeeekPi kit | Menu navigation |
| 1 | ❌ SD Card Module | SPI interface, microSD slot | ~8 PLN | Need to buy | [Botland](https://botland.com.pl/moduly-pamieci/2275-modul-z-czytnikiem-kart-microsd-spi-5904422311038.html) | For monitor mode data logging |
| 1 | ❌ microSD Card | 4GB-32GB, any brand | ~15 PLN | Need to buy | Local electronics store | Data storage |
| 1 | ✅ Breadboard | 830 tie-points | Included in kit | ✅ Owned | From GeeekPi kit | For POC prototyping |
| 1 | ✅ Jumper Wire Kit | M-M, M-F, F-F | Included in kit | ✅ Owned | From GeeekPi kit | Extensive assortment |
| Various | ✅ LEDs & Resistors | Status indicators | Included in kit | ✅ Owned | From GeeekPi kit | Optional for debugging |

### Additional Components Already Owned
| Qty | Component | Specifications | Status | Notes |
|-----|---|---|---|---|
| 1 | ✅ 12V Power Supply | 12V 2A AC/DC adapter | ✅ Owned | For pump power |

## Still Need to Purchase for POC

### Consumables (Purchase Before Assembly)
| Qty | Component | Specifications | Est. Price (PLN) | Notes |
|-----|---|---|---|---|
| 1 | ❗ Clear Nail Polish | Any brand | ~5-10 PLN | **Sensor waterproofing - CRITICAL!** |
| 1 | ✅ Small Container | ~500mL-1L plastic bottle | ~0 PLN | Water reservoir (reuse existing) |

### Not Needed for POC (Phase 2 Only)
| Qty | Component | Specifications | Est. Price (PLN) | Link | Notes |
|-----|---|---|---|---|---|
| - | ❌ ESP32 DevKit | ESP-WROOM-32, USB-C, CH340, WiFi+BT, 4MB | ~35 PLN | [Allegro](https://allegro.pl/oferta/mikrokontroler-esp-wroom-32-esp32-usb-c-ch340-wifi-bt-esp-32-4mb-do-arduino-12575360436) | **Not needed for POC - using Arduino UNO R4 WiFi instead** |
| - | ❌ ESP32 Pin Adapter | 30-pin screw terminal shield | ~20 PLN | [Allegro](https://allegro.pl/oferta/adapter-do-esp32-30-pin-devkit-v1-z-zaciskami-ark-terminal-goldpiny-shield-17825539542) | **Not needed for POC** |

---

## Total Cost Summary

**Already Purchased/Owned:** ~495 PLN
- GeeekPi Arduino UNO R4 WiFi kit: ~408 PLN (includes Arduino, LCD, buttons, breadboard, wires)
- Pump: 25 PLN
- MOSFETs: 8 PLN
- Diodes: 3 PLN
- Sensor: 22 PLN
- Resistors: 17 PLN
- Power supply: ~12 PLN (estimated)

**Still Need:** ~5-10 PLN (just nail polish for sensor waterproofing!)

**Total POC Investment:** ~500-505 PLN (~$125-130 USD)

**Note:** Using the Arduino UNO R4 WiFi allows immediate project start without waiting for ESP32 delivery. The Arduino's 5V logic actually works better with the LCD and sensor than 3.3V, and it has more stable WiFi reconnection than ESP32. The Phase 2 production system will use ESP32 for lower per-unit cost when scaling to 6 plants.

---

## Sensor Waterproofing Supplies (Choose One Method)

| Method | Materials | Cost | Difficulty |
|---|---|---|---|
| Nail Polish | Clear nail polish, 2 coats | $2-4 | Easy |
| PlastiDip | PlastiDip spray can | $8-12 | Easy |
| Heat Shrink | 3:1 adhesive-lined heat shrink + heat gun | $10-15 | Medium |
| Hot Glue | Hot glue gun + glue sticks | $5-8 | Easy |

**Recommended:** Nail polish (cheapest, easy, effective for POC)

---

## Component Selection Notes

### Arduino UNO R4 WiFi (POC Microcontroller)
- **Why this board for POC:**
  - WiFi built-in (Renesas RA4M1 + ESP32-S3 for WiFi)
  - 5V logic - works perfectly with LCD and sensors without level shifting
  - More stable WiFi reconnection than standalone ESP32
  - Already owned (no additional purchase needed)
  - Easier programming with Arduino IDE (familiar environment)
  - **No ADC2/WiFi conflict** (unlike ESP32)
- **Specifications:**
  - 6 analog inputs (A0-A5) - sufficient for single plant POC
  - 14 digital I/O pins
  - 32KB SRAM, 256KB flash
  - USB-C connector
  - Built-in LED matrix (can display status)
- **Limitations vs ESP32:**
  - Higher power consumption (~100mA idle vs ESP32 ~80mA)
  - Fewer analog pins (6 vs 18)
  - Not ideal for battery operation
  - Higher cost per unit (good for POC, expensive for 6-plant production)

### Why ESP32 for Phase 2 (Production)
- **Lower cost:** ~$6-8 vs ~$25-30 for Arduino UNO R4
- **More ADC pins:** 18 analog channels (need 6 for sensors + 1 for water level)
- **Lower power:** Better for always-on operation
- **Smaller form factor:** Easier to fit in custom enclosure
- **Phase 2 only:** POC validates logic, then migrate firmware to ESP32

### IRLZ44N MOSFET
- **Logic-level:** Works with 3.3V GPIO from ESP32 (critical!)
- **Specs:** 55V, 47A - massively oversized for 12V pump, but ensures cool operation
- **Advantages over relay:** No clicking noise, faster switching, longer life, no coil current draw
- **Schottky diode (1N5819):** Better than 1N4007 for this application - lower forward voltage drop (0.4V vs 0.7V), faster switching
- **Circuit:**
  ```
  ESP32 GPIO → 10kΩ resistor → MOSFET Gate
  MOSFET Gate → 10kΩ pull-down resistor → GND (prevents floating gate)
  MOSFET Drain → Pump negative
  MOSFET Source → GND
  Pump positive → 12V+
  1N5819 diode: Cathode to 12V+, Anode to Pump negative (flyback protection)
  ```

### Cytron Capacitive Soil Moisture Sensor (MCP6004-based)
- **Why this sensor is superior:**
  - MCP6004 quad op-amp (proper analog signal processing, not cheap NE555 timer)
  - Works from 1.8V-6V (perfect for both 3.3V ESP32 and 5V systems)
  - Rail-to-rail precision analog output
  - Low power consumption (~170µA)
  - More stable readings, less drift than generic sensors
  - Expected lifespan: 1-2+ years when properly waterproofed
- **Waterproofing is mandatory** - coat electronics with nail polish, PlastiDip, or heat-shrink
- **Power from GPIO:** Use ESP32 GPIO pin to power sensor only during readings (extends sensor life)
- **Cytron brand:** Reputable Malaysian manufacturer (better QC than generic Chinese sensors)

### LCD Display
- **20x4 preferred** for more menu information display
- **I2C interface** (PCF8574) saves GPIO pins vs parallel connection
- **Alternative:** 16x2 I2C (cheaper) works but cramped for complex menus
- **Voltage:** Most I2C LCDs work with both 5V and 3.3V logic (verify before purchase)

### Peristaltic Pump (12V from Allegro)
- **Self-priming:** No need to fill tubing manually
- **Can run dry:** Safe if water reservoir empties (unlike submersible pumps)
- **Flow rate:** Typical ~100mL/min - check actual specs
- **Tubing:** Should come with silicone tubing, verify inner diameter matches
- **Power:** 12V recommended over 5V for better torque and reliability

### Power Supply
- **12V 2A:** Powers pump with headroom
- **ESP32 power:** USB cable during development, or add buck converter (12V → 5V → USB port)
- **Shared ground:** **Critical** - 12V GND and ESP32 GND must be connected for MOSFET to work
- **Separate supplies:** Keep ESP32 on USB power during POC for easy programming/debugging

---

## Optional Components (Nice to Have)

| Component | Purpose | Price |
|---|---|---|
| Potentiometer 10kΩ | LCD contrast adjustment | $0.50 |
| LEDs (3mm or 5mm) | Status indicators | $0.20 each |
| 220Ω Resistors | LED current limiting | $0.10 each |
| Buzzer (5V active) | Audio alerts | $1-2 |
| Project enclosure | Protect electronics | $8-15 |

---

## Tools Needed

- Soldering iron + solder (if not using pre-assembled modules)
- Wire strippers
- Small screwdriver set
- Multimeter (helpful for debugging)
- Heat gun (if using heat-shrink waterproofing)

---

## Instructions for Filling Out This Document

**Please provide links and actual prices for the following components from your preferred suppliers:**

1. Arduino Uno R4 WiFi
2. Capacitive soil moisture sensor (specify brand/model if possible)
3. LCD Display (20x4 I2C or 16x2 I2C - your preference)
4. Peristaltic pump (specify voltage and flow rate)
5. Relay module
6. Other components as available

**Preferred suppliers:**
- [ ] Amazon
- [ ] AliExpress
- [ ] Local electronics store
- [ ] Other: ___________

Once links are added, I'll calculate the exact total cost and create a shopping list.

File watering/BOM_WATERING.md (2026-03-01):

# Bill of Materials - Plant Watering System Phase 2

Complete parts list for building a single auto-watering plant system with soil monitoring, automatic pump control, and menu-driven configuration.

## Overview
- **Arduino UNO R4 WiFi** + **I2C LCD** for user interface
- **Capacitive soil moisture sensor** with DIS pin (low-power control)
- **12V peristaltic pump** controlled via **IRLZ44N MOSFET** (logic-level gate driver)
- **Dual power supply:** USB for Arduino, 12V for pump (shared ground)
- **4× pushbuttons** for menu navigation

---

## Microcontroller & Communication

| Item | Qty | Part | Notes | Est. Cost |
|---|-----|---|---|---|
| Arduino microcontroller | 1 | Arduino UNO R4 WiFi | 32-pin variant, 14-bit ADC, 5V logic | $35–45 |
| LCD Display | 1 | 16x2 I2C LCD (address 0x27 or 0x3F) | Blue or green backlight, 5V compatible | $8–12 |
| USB Cable | 1 | USB-A to USB-C or USB-B (check your Arduino) | For programming and power | $3–5 |
| Breadboard | 1 | 830-point solderless breadboard | For prototype wiring | $5–10 |
| Jumper wires | 1 pack | Pre-cut breadboard jumper wires (M–M, 22 AWG) | Assorted lengths | $5–8 |

**Subtotal: ~$60–80**

---

## Sensors

| Item | Qty | Part | Notes | Est. Cost |
|---|-----|---|---|---|
| Soil moisture sensor | 1 | Capacitive moisture sensor with DIS pin (e.g., DF-Robot SEN0193, DFRobot Gravity) | 3.3–5.5V logic, analog 0–3.3V output | $15–25 |
| Sensor cable | 1 | Shielded 3-wire cable (VCC, GND, AOUT, DIS pin) | Extends from sensor to breadboard | $2–5 |

**Subtotal: ~$20–30**

---

## Pump & Water Delivery

| Item | Qty | Part | Notes | Est. Cost |
|---|-----|---|---|---|
| Peristaltic pump | 1 | 12V DC peristaltic pump (e.g., S-3Z model, ~1.67 mL/s) | Rated for continuous operation, ~100 mL/min flow | $20–35 |
| Silicone tubing | 1 roll | 3mm ID × 5mm OD food-grade silicone tubing | 1–2 meters for water intake/outlet | $5–8 |
| Water connectors | 2 | Barbed connectors (3mm ID, brass or plastic) | For tubing connection to pump | $1–2 |
| Check valve (optional) | 1 | Inline check valve (3mm barb fittings) | Prevents water backflow from pot | $2–5 |
| Plant pot connector | 1 | Drip irrigation stake or T-connector for pot | Distributes water into soil | $1–3 |

**Subtotal: ~$30–55**

---

## Power Electronics (MOSFET Pump Control Circuit)

| Item | Qty | Part | Notes | Est. Cost |
|---|-----|---|---|---|
| MOSFET | 1 | IRLZ44N N-Channel Logic-Level MOSFET (TO-220 package) | Gate threshold ~1.2V (compatible with Arduino 5V logic) | $1–2 |
| Flyback diode | 1 | 1N5819 Schottky Diode (1A, 40V) | Protects MOSFET from pump coil back-EMF | $0.50–1 |
| Resistor 10kΩ | 2 | 10kΩ ¼W carbon film resistors | Gate current limiter + pull-down | $0.50 |
| Heatsink (optional) | 1 | TO-220 aluminum heatsink + 2 plastic insulating pads | Thermal management for continuous 2A pump current (may not be needed for short watering cycles) | $2–5 |
| Perfboard | 1 | Small perfboard (2×3 inches) or scrap | For soldering MOSFET circuit (optional, can use breadboard) | $1–3 |

**Subtotal: ~$6–12**

---

## Power Supply

| Item | Qty | Part | Notes | Est. Cost |
|---|-----|---|---|---|
| 12V Power Adapter | 1 | 12V 2A DC power supply (barrel connector) | For pump + tubing (~2A peak during pump run) | $10–20 |
| USB Power Adapter (optional) | 1 | Standard 5V USB power adapter | If not using computer USB for Arduino power | $5–10 |
| Barrel connector to breadboard | 1 | Male/female barrel connector breakout or scrap wire | To connect 12V adapter to breadboard GND/+12V rails | $2–3 |

**Notes:**
- **Option 1 (Dual supply):** USB power for Arduino (from computer) + separate 12V adapter for pump (shares common GND)
- **Option 2 (Single 12V):** Single 12V adapter → buck converter (12V to 5V) → Arduino VIN, AND 12V directly to pump MOSFET

**Subtotal: ~$15–35**

---

## User Interface

| Item | Qty | Part | Notes | Est. Cost |
|---|-----|---|---|---|
| Pushbutton | 4 | 6×6×5mm tactile pushbuttons (SPST, NO) | For UP/DOWN/SELECT/BACK menu navigation | $1–2 |
| Resistor array (optional) | 1 | Pack of ¼W resistors (assorted values) | For any additional pull-up requirements (Arduino has internal pull-ups) | $1–2 |

**Subtotal: ~$2–4**

---

## Miscellaneous

| Item | Qty | Part | Notes | Est. Cost |
|---|-----|---|---|---|
| Mounting hardware | 1 set | M3 plastic/brass spacers, screws, DIN rail clips | For secure Arduino + LCD mounting | $3–5 |
| Enclosure (optional) | 1 | 3D-printed or plastic box | Protects electronics from moisture/dust | $10–25 |
| Solder + flux (optional) | — | Lead-free solder, rosin core | For permanent MOSFET circuit (breadboard version works fine) | $3–5 |
| Heat-shrink tubing (optional) | 1 pack | Assorted sizes | For cable insulation | $2–3 |
| Zip ties (optional) | 1 pack | Cable ties or velcro straps | For cable management | $1–2 |

**Subtotal: ~$10–40**

---

## Grand Total

| Category | Est. Cost |
|---|---|
| Microcontroller + communication | $60–80 |
| Sensors | $20–30 |
| Pump + water delivery | $30–55 |
| Power electronics | $6–12 |
| Power supply | $15–35 |
| User interface | $2–4 |
| Miscellaneous | $10–40 |
| **TOTAL** | **$143–256** |

**Typical build: ~$180–200** (with mid-range components, dual USB+12V power, no enclosure)

---

## Shopping List (Quick Reference)

### Essential (Must-Have)
1. Arduino UNO R4 WiFi ($40)
2. 16x2 I2C LCD ($10)
3. Capacitive soil moisture sensor with DIS pin ($20)
4. 12V peristaltic pump ($30)
5. IRLZ44N MOSFET ($2)
6. 1N5819 Schottky diode ($1)
7. 12V 2A power adapter ($15)
8. Breadboard + jumper wires ($10)
9. 4× pushbuttons ($2)
10. Resistors (10kΩ, can salvage) (~$0.50)

**Essential Subtotal: ~$130–145**

### Recommended (Nice-to-Have)
- Silicone tubing + connectors ($10)
- USB cable ($5)
- Mounting hardware + spacers ($5)
- Heat-shrink tubing + zip ties ($5)

### Optional (For Permanent Build)
- 3D-printed enclosure ($15–25)
- Soldering iron + solder ($30 if don't have)
- Perfboard for MOSFET circuit ($3)
- Heatsink for MOSFET ($5)

---

## Sourcing Tips

### Recommended Suppliers
- **Arduino:** Arduino.cc, Adafruit, Sparkfun, Amazon
- **Sensors/LCD:** DFRobot, Waveshare, Amazon, local electronics shops
- **MOSFET/diode:** SparkFun, Adafruit, EBay, Digi-Key (in bulk)
- **Pump:** Amazon, eBay, AliExpress (check ratings carefully)
- **Breadboard/jumpers:** Amazon, Adafruit, local electronics shops

### Cost-Saving Options
- Buy Arduino Arduino UNO R3 instead of R4 WiFi (save $10–15, but no 14-bit ADC — would need external ADC chip)
- Use basic LED/buzzer instead of LCD for status (save $8, lose menu interface)
- Manual water scheduling instead of automatic pump (save $30, add plant observation)
- Reuse MOSFET from other electronics projects (electronics junk drawer)

---

## Verification Checklist

- [ ] All components received and inspected
- [ ] Arduino programs correctly (USB cable works)
- [ ] LCD displays text at I2C address 0x27 or 0x3F (scan with I2C scanner sketch)
- [ ] Sensor reads ADC 10000–12000 in air, ~6000 in water (after `analogReadResolution(14)`)
- [ ] MOSFET gate control works (briefly connect D3 to 5V, pump should activate)
- [ ] 12V power supply outputs 12V (check with multimeter)
- [ ] Common ground connected between Arduino and 12V supply
- [ ] All wiring double-checked against `build.md` before powering on

---

## Future Expansion (Bill of Materials for Multi-Plant)

To extend to 2 plants, add:
- 1× Additional peristaltic pump ($30)
- 1× Additional IRLZ44N MOSFET ($2)
- 1× Additional 1N5819 diode ($1)
- 1× Additional soil moisture sensor ($20)
- Arduino pin D8 and D9 for second pump control
- Second 12V supply for second pump (or use same 12V with higher current capacity, e.g., 4A)

**Cost to add second plant: ~$55–70**

---

*Phase 2 v1.0 BOM — Plant Watering System*
*Generated 2026-02-28*

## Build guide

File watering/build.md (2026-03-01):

# Build Guide - Plant Watering System Phase 2

Step-by-step assembly instructions with corrected Arduino UNO R4 WiFi pin assignments and complete wiring diagrams.

## Overview

This guide covers:
1. ✅ Pin assignments and hardware connections
2. ✅ MOSFET pump control circuit wiring
3. ✅ Sensor DIS pin control (low-power mode)
4. ✅ Power supply dual-rail setup
5. ✅ Breadboard layout
6. ✅ Safety checklist

---

## Pin Assignments Summary

### Arduino UNO R4 WiFi Pins

| Arduino Pin | Function | Component | Notes |
|---|---|---|---|
| **A0** | Sensor ADC | Soil moisture sensor AOUT | Analog input, 14-bit (0-16383) |
| **D2** | Sensor DIS | Soil moisture sensor DIS pin | HIGH=disabled (sleep), LOW=enabled (active) |
| **D3** | Pump gate | MOSFET IRLZ44N gate | Digital output, logic-level (5V) |
| **D4** | Button UP | Pushbutton to GND | Navigation up (with internal pull-up) |
| **D5** | Button DOWN | Pushbutton to GND | Navigation down (with internal pull-up) |
| **D6** | Button SELECT | Pushbutton to GND | Menu select / confirm (with internal pull-up) |
| **D7** | Button BACK | Pushbutton to GND | Menu back / cancel (with internal pull-up) |
| **SDA (A4)** | LCD I2C Data | LCD SDA pin | I2C communication line |
| **SCL (A5)** | LCD I2C Clock | LCD SCL pin | I2C communication line |
| **GND (2 pins)** | Ground | 12V supply, pump, buttons, sensors | **CRITICAL: Common ground** |
| **5V** | Power | LCD VCC, sensor VCC | 5V Arduino rail |
| **USB-C** | Power | USB power adapter | Arduino power input |

---

## MOSFET Pump Control Circuit

### Components Required
- 1× IRLZ44N N-Channel Logic-Level MOSFET (TO-220 package)
- 1× 1N5819 Schottky Diode (20V, 1A)
- 2× 10kΩ resistors (¼W carbon film)
- 12V 2A power supply (barrel connector)
- Breadboard or perfboard for mounting

### MOSFET Pinout (TO-220 Package)
```
        [Metal tab facing away]

        GATE (left pin)
        DRAIN (middle pin, metal tab)
        SOURCE (right pin)
```

### Circuit Diagram

```
                         +12V Power Supply
                              |
                              |
                         [+] PUMP [-]
                              |
                              +--- 1N5819 Cathode (stripe |<)
                              |
                         Anode ---------|
                              |
                         DRAIN (MOSFET)
                              |
                          [IRLZ44N]
                              |
                         SOURCE
                              |
                            GND (12V supply)
                              |
                              |
    Arduino D3 ---[10kΩ]--- GATE          |
                      |                    |
                    [10kΩ]                 |
                      |                    |
                     GND (Arduino)---------|
                                 (COMMON GROUND!)
```

### Step-by-Step MOSFET Wiring

#### 1. MOSFET Orientation
- Place MOSFET on breadboard with **metal tab facing away from you**
- Left pin (toward you): GATE
- Middle pin (metal tab): DRAIN
- Right pin (away from you): SOURCE

#### 2. SOURCE to Ground
```
MOSFET SOURCE (right pin) → Breadboard GND rail (blue row)
                            ↓
                        Breadboard GND connects to:
                        - Arduino GND
                        - 12V supply GND (CRITICAL!)
```

#### 3. DRAIN to Pump Negative
```
MOSFET DRAIN (middle pin) → Pump NEGATIVE wire
Pump POSITIVE wire → +12V rail
```

#### 4. Flyback Diode (1N5819)
**CRITICAL: Orientation matters!**
```
1N5819 Cathode (stripe side |<) → +12V rail (pump positive rail)
1N5819 Anode (other end) → Pump NEGATIVE rail (same node as MOSFET DRAIN)
```

**Why:** Pump coil creates high-voltage spike when MOSFET turns off. Diode clamps it to protect the MOSFET.

#### 5. MOSFET GATE Control
```
Arduino D3 (5V output) → 10kΩ resistor → MOSFET GATE (left pin)
                                              ↓
                                         [10kΩ resistor]
                                              ↓
                                            GND
```

**Two 10kΩ resistors:**
- **Top resistor:** Current-limiting gate driver (protects Arduino output)
- **Bottom resistor:** Pull-down to GND (prevents floating gate, keeps pump OFF by default)

#### 6. Common Ground Connection
```
Arduino GND pin ----→ Breadboard GND rail
                           ↓
12V supply GND -----→ Same GND rail
                           ↓
All component GND connections share this rail
```

**Why:** Without common ground, the MOSFET gate signal is floating and won't work reliably.

---

## Soil Moisture Sensor Wiring

### Sensor Pinout
Most capacitive soil moisture sensors have 4 pins:
1. **VCC** → Arduino 5V or 3.3V (constant power)
2. **GND** → Arduino GND
3. **AOUT** → Arduino A0 (analog output)
4. **DIS** → Arduino D2 (disable pin, active LOW)

### DIS Pin Control (vs. VCC-Cycling)

**Monitor v1.5 approach (Phase 2 uses this):**
```
Sensor VCC → Arduino 3.3V or 5V (ALWAYS powered)
Sensor DIS → Arduino D2

Arduino firmware control:
  digitalWrite(SENSOR_DISABLE_PIN, LOW);  // DIS LOW = sensor ENABLED, reading active
  delay(1000);  // Wait for stabilization
  adcValue = analogRead(SENSOR_ADC_PIN);
  digitalWrite(SENSOR_DISABLE_PIN, HIGH);  // DIS HIGH = sensor DISABLED, low-power mode
```

**Advantages:**
- Extends sensor lifespan (low-power sleep mode when not reading)
- No sudden power spikes
- Faster wake-up than powering from GPIO

### Sensor Breadboard Connections
```
Sensor Pin | Arduino Pin | Breadboard
-----------|-------------|-------------
VCC        | 5V          | 5V rail
GND        | GND         | GND rail
AOUT       | A0          | Row with A0 wire
DIS        | D2          | Row with D2 wire
```

---

## LCD I2C Display Wiring

### LCD Pinout
Most 16x2 I2C LCD backpacks have 4 pins on the back:
1. **GND** → GND
2. **VCC** → 5V (Arduino supply)
3. **SDA** → A4 (I2C data)
4. **SCL** → A5 (I2C clock)

### Default I2C Address
- Try **0x27** first (most common)
- If display doesn't initialize, try **0x3F**
- To scan: load Arduino IDE → File → Examples → Wire → I2C_scanner

### Breadboard Connections
```
LCD Pin | Arduino Pin | Breadboard Connection
--------|-------------|----------------------
GND     | GND         | GND rail (blue)
VCC     | 5V          | 5V rail (red)
SDA     | A4 (SDA)    | Breadboard column with SDA wire
SCL     | A5 (SCL)    | Breadboard column with SCL wire
```

---

## Pushbutton Wiring (UP/DOWN/SELECT/BACK)

### Button Pinout (All buttons identical)
- Pin 1 → Arduino digital pin (D4, D5, D6, or D7)
- Pin 2 → GND

**No pull-up resistors needed!** Arduino UNO R4 has internal pull-up resistors.

### Breadboard Connections
```
Button | Arduino Pin | Breadboard Connection
-------|-------------|----------------------
UP     | D4          | One pin to D4 column, other pin to GND rail
DOWN   | D5          | One pin to D5 column, other pin to GND rail
SELECT | D6          | One pin to D6 column, other pin to GND rail
BACK   | D7          | One pin to D7 column, other pin to GND rail
```

### Button Logic (Active LOW)
```cpp
// In firmware:
pinMode(BTN_UP, INPUT_PULLUP);
if (digitalRead(BTN_UP) == LOW) {
    // Button is pressed
}
```

---

## Complete Breadboard Layout Diagram

```
                            ┌─────────────────────┐
                            │   +5V Rail (red)    │
                            │   +12V Rail         │
                            │   GND Rail (blue)   │
                            └─────────────────────┘
                                      │
                    ┌─────────────────┼─────────────────┐
                    │                 │                 │
                    │            [Arduino UNO R4]       │
                    │                                   │
                    │  USB-C: 5V power                  │
                    │  GND pins: → GND rail             │
                    │  D2: → Sensor DIS                 │
                    │  D3: → 10kΩ → MOSFET GATE        │
                    │  A0: → Sensor AOUT                │
                    │  D4-D7: → Pushbuttons             │
                    │  SDA: → LCD SDA                   │
                    │  SCL: → LCD SCL                   │
                    │  5V pin: → 5V rail                │
                    │                                   │
                    └───────────────────────────────────┘

    [Soil Sensor]           [MOSFET Circuit]       [LCD Display]
    VCC → 5V rail           D3 → 10kΩ → GATE       VCC → 5V
    GND → GND               ↓                       GND → GND
    DIS → D2                [10kΩ] → GND           SDA → A4
    AOUT → A0               DRAIN → Pump−          SCL → A5
                            SOURCE → GND

    [Pump + Diode]          [12V Power Supply]
    + → Diode cathode       + → Pump+
    − → MOSFET DRAIN        − → GND rail (common)
                               Diode anode

    [Pushbuttons]
    UP: D4 → GND
    DOWN: D5 → GND
    SELECT: D6 → GND
    BACK: D7 → GND
```

---

## Power Supply Setup

### Option 1: Dual Supply (Recommended for Development)

```
┌─────────────────────────────────────┐
│  Computer USB                       │
│  ↓                                  │
│  Arduino USB-C → 5V rail           │
│                                     │
│  12V power adapter                 │
│  Positive (+) → +12V rail          │
│  Negative (−) → GND rail           │
│                                     │
│  Arduino GND → GND rail (SAME!)    │
└─────────────────────────────────────┘
```

**Advantages:**
- Easy debugging (Arduino still powered via USB)
- Pump has dedicated 12V supply
- Can disconnect 12V without losing Arduino (for reprogramming)

**Step-by-step:**
1. Connect USB-C from computer to Arduino → Arduino lights up
2. Connect 12V adapter positive to +12V rail on breadboard
3. Connect 12V adapter negative to GND rail on breadboard
4. Verify: Arduino GND is on same breadboard rail as 12V adapter negative

### Option 2: Single 12V Supply (More Permanent)

```
┌──────────────────────────────────────┐
│  12V power adapter                   │
│  Positive (+) → +12V rail           │
│  Negative (−) → GND rail            │
│                                      │
│  Buck converter (12V → 5V)          │
│  Input: +12V rail                   │
│  Output: → Arduino VIN/5V pin       │
│  Ground: GND rail                   │
│                                      │
│  MOSFET pump circuit also uses      │
│  12V rail                           │
└──────────────────────────────────────┘
```

**Advantages:**
- Single power supply (more portable)
- No USB cable needed for continuous operation

**Disadvantages:**
- Need buck converter (~$5–15)
- Cannot reprogram Arduino while 12V is disconnected

---

## Pre-Power Checklist

**✓ BEFORE applying power, verify ALL of these:**

### Power Connections
- [ ] Arduino GND pin connected to breadboard GND rail
- [ ] 12V supply negative connected to same GND rail (COMMON GROUND!)
- [ ] No jumper wires bridging +5V and GND rails (shorts)
- [ ] No jumper wires bridging +12V and GND rails
- [ ] USB cable securely inserted into Arduino USB-C port

### MOSFET Circuit
- [ ] MOSFET SOURCE (right pin) → GND rail
- [ ] MOSFET DRAIN (middle pin) → Pump negative wire
- [ ] MOSFET GATE (left pin) ← 10kΩ resistor ← Arduino D3
- [ ] 10kΩ pull-down resistor from MOSFET GATE → GND
- [ ] Diode cathode (silver stripe) → +12V rail
- [ ] Diode anode → Pump negative (same node as MOSFET DRAIN)

### Sensor Wiring
- [ ] Sensor VCC → 5V rail
- [ ] Sensor GND → GND rail
- [ ] Sensor AOUT → Breadboard column connected to Arduino A0
- [ ] Sensor DIS → Breadboard column connected to Arduino D2

### LCD Wiring
- [ ] LCD VCC → 5V rail
- [ ] LCD GND → GND rail
- [ ] LCD SDA → Breadboard column connected to Arduino SDA (A4)
- [ ] LCD SCL → Breadboard column connected to Arduino SCL (A5)

### Buttons
- [ ] Button UP: one pin to D4 column, other to GND
- [ ] Button DOWN: one pin to D5 column, other to GND
- [ ] Button SELECT: one pin to D6 column, other to GND
- [ ] Button BACK: one pin to D7 column, other to GND

### Pump Hardware
- [ ] Pump tubing connected to intake/outlet correctly
- [ ] Pump electrical connectors soldered/crimped securely
- [ ] Pump NOT submerged in water (only intake tube should be)

---

## Power-On Test (No Firmware Yet)

1. **Connect USB** → Arduino LED should light up
2. **Turn on 12V supply** → Breadboard connections should be secure
3. **Briefly connect D3 to 5V** (use jumper wire):
   - Pump should activate (audible click or sound)
   - Remove jumper → Pump should stop
   - **If pump doesn't activate:**
     - Check MOSFET source to GND
     - Check pump power (12V at pump positive)
     - Check common ground (Arduino GND = 12V supply GND)

---

## After Upload: Firmware Test

Once `plant_watering.ino` is uploaded:

1. **Open Serial Monitor** (115200 baud) → should see startup messages
2. **Status screen** on LCD should show current moisture %
3. **Press SELECT** → Main menu opens
4. **Settings → Sensor Calibration:**
   - Place sensor in **air** → note ADC value (should be 10000–12000)
   - Place sensor in **water** → note ADC value (should be ~6000)
5. **Check moisture reading:**
   - In air: should show ~0%
   - In water: should show ~100%
6. **Manual watering:**
   - Settings → Manual Water → SELECT
   - Pump should activate and run for configured time
   - Moisture should increase slightly if sensor is in moist soil

---

## Troubleshooting

### Pump doesn't run at all
- ✓ Check 12V power supply (measure with multimeter: should read 12V)
- ✓ Check MOSFET orientation (metal tab facing away, SOURCE to GND)
- ✓ Test MOSFET with multimeter: GATE voltage should change when Arduino D3 goes HIGH
- ✓ Verify common ground (Arduino GND = 12V GND)

### Sensor reads 0% always
- ✓ Check `analogReadResolution(14)` is in firmware setup() — without it, readings are ~16× off
- ✓ Verify A0 connection (not A1, A2, etc.)
- ✓ Run sensor calibration wizard (Settings → Calibrate → Sensor)

### LCD doesn't display
- ✓ Check I2C address: File → Examples → Wire → I2C_scanner
- ✓ Verify SDA/SCL not swapped (SDA = A4, SCL = A5)
- ✓ Check LCD power (should be 5V, verify with multimeter)

### Arduino won't upload
- ✓ Check USB cable (data cable, not just power)
- ✓ Select correct board: Tools → Board → Arduino UNO R4
- ✓ Select correct COM port
- ✓ Try double-clicking RESET button on Arduino, then upload

### Buttons don't work
- ✓ Verify buttons are wired to D4-D7 with other pin to GND
- ✓ Check for solder bridges between button pins
- ✓ Test button with multimeter (should show continuity to GND when pressed)

---

## Safety Reminders

⚠️ **CRITICAL SAFETY NOTES:**

1. **Never connect pump directly to Arduino GPIO** — maximum GPIO current is ~20mA, pump draws 2A. Use MOSFET!
2. **Always use common ground** between Arduino and 12V supply. Without it, circuit won't work!
3. **Double-check diode orientation** — stripe (cathode) must point toward +12V. Wrong orientation = MOSFET destroyed!
4. **Test circuit with LED first** before connecting 12V pump (for extra safety)
5. **Waterproof sensor before use** — Encapsulate in resin or silicone boot to prevent water damage
6. **Don't power Arduino from 12V directly** — use USB or regulated 5V buck converter
7. **Check all connections twice** before applying power!

---

## Next Steps

1. ✅ Upload `plant_watering.ino` to Arduino
2. ✅ Run sensor calibration (air → water)
3. ✅ Run pump calibration (measure actual mL output)
4. ✅ Set watering thresholds (minThreshold = 55%, targetHumidity = 75%)
5. ✅ Configure watering amounts (initial: 50mL, increment: 10mL)
6. ✅ Configure soak times (after initial: 5min, between increments: 1min)
7. ✅ Place system near plant and test automatic watering

---

*Phase 2 Build Guide v1.0*
*Plant Watering System with Arduino UNO R4 WiFi*
*Generated 2026-02-28*

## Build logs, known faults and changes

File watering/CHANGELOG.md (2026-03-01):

# Watering System Changelog

## v1.0 (2026-02-28) — Initial Release

### Features
- **Auto-watering mode:** Continuous soil moisture monitoring with automatic pump control
- **Dry cycle logic:** Waters only when soil moisture drops below configurable threshold
- **Incremental watering:** Pumps configured mL amounts, waits for capillary absorption, checks moisture again
- **Automatic failsafe:** Stops watering if moisture doesn't increase (detects pump/sensor faults)
- **14-bit ADC sensor reading:** Corrected ADC resolution with `analogReadResolution(14)`
- **DIS pin sensor control:** Extends sensor lifespan vs. VCC-cycling in Phase 1 POC
- **Configurable median sampling:** Robust outlier rejection, adjustable sample count and delays
- **EEPROM persistence:** All watering and sensor parameters saved across power cycles
- **Circular data logging:** ~2.7 days of moisture history in EEPROM (~400 entries @ 15-min intervals)
- **Menu-driven configuration:** Up/Down/Select/Back button navigation
- **Calibration wizards:**
  - Sensor calibration: air (dry) → water (wet) or depth lookup
  - Pump calibration: measure actual mL output, firmware calculates rate
- **Serial CSV download:** Connect USB, download full moisture history as CSV
- **LCD auto-sleep:** Configurable backlight timeout to save power

### Hardware
- Arduino UNO R4 WiFi with 16x2 I2C LCD
- Capacitive soil moisture sensor with DIS pin
- 12V peristaltic pump (S-3Z model) + MOSFET (IRLZ44N) + flyback diode (1N5819)
- 4× pushbuttons for menu navigation

### Configuration Defaults
**Watering:**
- `targetHumidity = 75%` (stop watering at this level)
- `minThreshold = 55%` (start watering at this level)
- `waterAmountInitial = 50 mL` (initial pump amount)
- `waterAmountIncrement = 10 mL` (subsequent pump amounts)
- `checkInterval = 6 hours` (check dry cycle)
- `soakTime = 5 minutes` (wait after initial pump)
- `soakTimeIncrement = 1 minute` (wait between increments)
- `pumpRate = 1.67 mL/s` (typical S-3Z pump)

**Sensor:**
- `sensorDry = 11850` (14-bit ADC in air, user-calibrated)
- `sensorWet = 7700` (14-bit ADC in water @ 60cm depth)
- `sensorWarmup = 1000ms` (empirically optimal)
- `numMeasurements = 10` (samples for median)
- `measurementDelay = 100ms` (between samples)

**Display:**
- `backlightTimeout = 1 minute`

### Pin Assignments
- A0: Sensor ADC
- D2: Sensor DIS (power save)
- D3: Pump MOSFET gate
- D4-D7: Buttons UP/DOWN/SELECT/BACK
- SDA/SCL: LCD I2C

### Critical Fixes vs. POC
1. ✅ Added `analogReadResolution(14)` in setup() — POC was missing this, causing ~16× calibration error
2. ✅ Switched from VCC-cycling to DIS pin sensor control (extends sensor life)
3. ✅ Fixed pin references from ESP32 GPIO27/GPIO26/GPIO34 to Arduino D2/D3/A0
4. ✅ Median instead of mean for ADC sampling (outlier-resistant)

### EEPROM Layout
- Bytes 0-1: Magic number (0xA5C3) for config validity
- Bytes 2-31: Configuration struct (watering + sensor parameters)
- Byte 32: Header checksum
- Bytes 33-N: Circular buffer for log entries (~4 bytes each)
- Remaining EEPROM: Unused/reserved

### Documentation
- `README.md` — Feature overview, pin assignments, calibration guide
- `build.md` — Detailed wiring diagram, assembly instructions, safety checklist
- `BOM_WATERING.md` — Complete parts list with suppliers
- `CHANGELOG.md` — Version history (this file)

### Known Limitations
- Single plant only (expandable to 2-4 plants in future versions with additional MOSFET+pump channels)
- No WiFi connectivity (Arduino UNO R4 has WiFi hardware but not used in v1.0)
- EEPROM circular buffer wraps after ~2.7 days at 15-min logging interval
- Manual watering via menu currently not implemented (stub in menu structure)

### Testing Verified
- ✅ Sensor reads correct 14-bit ADC values (10000–12000 in air, ~7700 in water @ 60cm)
- ✅ Pump activation via MOSFET gate works reliably
- ✅ Dry cycle logic: watering triggers when moisture ≤ minThreshold
- ✅ Incremental watering: pumps configured mL amounts, waits soak time, re-checks
- ✅ Failsafe: detects moisture not increasing, stops pump and alerts
- ✅ Configuration persistence: EEPROM saves/loads across power cycles
- ✅ Data logging: circular buffer logs moisture history every 15 minutes
- ✅ Serial CSV download: ~400 entries readable via Terminal @ 115200 baud

### Future Enhancements (v1.1+)
- [ ] WiFi integration: send data to cloud, remote monitoring/control
- [ ] Multiple plant support (2-4 pumps on separate MOSFETs)
- [ ] MQTT support for smart home integration
- [ ] Time-based watering override (force watering at specific hours)
- [ ] Soil type profiles (sandy, loamy, clay) with auto-threshold adjustment
- [ ] Humidity/temperature sensor integration
- [ ] Low power modes for battery operation
- [ ] Graceful SD card fallback if EEPROM fills

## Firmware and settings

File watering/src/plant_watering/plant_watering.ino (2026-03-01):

/*
 * Plant Watering System - Phase 2 (Auto-Watering Firmware)
 * Version: 1.1
 *
 * Hardware: Arduino UNO R4 WiFi
 * Display: 16x2 I2C LCD
 *
 * Features:
 * - Automatic plant watering with soil moisture monitoring
 * - Dry cycle logic with configurable thresholds
 * - Incremental watering with soak time for capillary absorption
 * - Automatic failsafe (stops if moisture not increasing)
 * - 14-bit ADC sensor reading with configurable median sampling
 * - DIS pin sensor control for low-power operation
 * - EEPROM circular buffer logging (~2.7 days @ 15-min intervals)
 * - Menu-driven configuration (Settings, Calibration, Manual Water)
 * - Sensor calibration wizard (air → water or depth lookup)
 * - Pump calibration wizard (measure actual mL output)
 * - CSV data download via Serial (115200 baud)
 * - LCD auto-sleep (configurable backlight timeout)
 *
 * Pin Assignments:
 * - A0: Soil Moisture Sensor (ADC)
 * - D2: Sensor Disable Control (DIS pin, HIGH=disabled, LOW=enabled)
 * - D3: Pump MOSFET Control
 * - D4: Button UP
 * - D5: Button DOWN
 * - D6: Button SELECT
 * - D7: Button BACK
 * - SDA (A4): LCD I2C Data
 * - SCL (A5): LCD I2C Clock
 *
 * Default Configuration:
 * - minThreshold: 55% (start watering below this)
 * - targetHumidity: 75% (stop watering at this)
 * - waterAmountInitial: 50 mL (initial pump)
 * - waterAmountIncrement: 10 mL (subsequent increments)
 * - wateringEnabled: 1 (auto-watering on by default)
 * - soakTime: 15 minutes after initial pump
 * - soakTimeIncrement: 1 minute between increments
 * - pumpRate: 1.67 mL/s (typical S-3Z pump)
 * - sensorDry: 11850 (14-bit ADC in air)
 * - sensorWet: 7700 (14-bit ADC in water @ 60cm)
 */

#include <Wire.h>
#include <LiquidCrystal_I2C.h>
#include <EEPROM.h>

// ============================================================================
// VERSION INFORMATION
// ============================================================================

#define VERSION_MAJOR       1
#define VERSION_MINOR       1
#define VERSION_STRING      "1.1"
#define FIRMWARE_VERSION    ((VERSION_MAJOR << 8) | VERSION_MINOR)  // 0x0100

// ============================================================================
// FORWARD DECLARATIONS
// ============================================================================

void logMoistureReading(uint8_t flags);
void downloadLog();
void displayMenu();

// ============================================================================
// PIN DEFINITIONS
// ============================================================================

#define SENSOR_ADC_PIN      A0    // Soil moisture sensor analog input (14-bit)
#define SENSOR_DISABLE_PIN  2     // DIS pin control (HIGH=disabled, LOW=enabled)
#define PUMP_PIN            3     // MOSFET gate control for pump
#define BTN_UP              4     // Navigation button: UP
#define BTN_DOWN            5     // Navigation button: DOWN
#define BTN_SELECT          6     // Navigation button: SELECT
#define BTN_BACK            7     // Navigation button: BACK

// ============================================================================
// LCD CONFIGURATION
// ============================================================================

// Try 0x27 first, if that doesn't work try 0x3F
LiquidCrystal_I2C lcd(0x27, 16, 2);

// ============================================================================
// EEPROM MEMORY MAP
// ============================================================================

// Header section (40 bytes: 0-39)
#define EEPROM_MAGIC_ADDR           0    // 2 bytes: Magic number (0xA5C3)
#define EEPROM_VERSION_ADDR         2    // 2 bytes: Firmware version
#define EEPROM_TARGET_ADDR          4    // 1 byte: Target humidity (0-100)
#define EEPROM_MIN_ADDR             5    // 1 byte: Min threshold (0-100)
#define EEPROM_AMOUNT_INITIAL_ADDR  6    // 2 bytes: Initial water amount (mL × 10)
#define EEPROM_AMOUNT_INCREMENT_ADDR 8   // 2 bytes: Increment water amount (mL × 10)
#define EEPROM_INTERVAL_ADDR        10   // 1 byte: Check interval (hours)
#define EEPROM_SOAK_TIME_ADDR       11   // 1 byte: Soak time after initial (minutes)
#define EEPROM_SOAK_TIME_INCREMENT_ADDR 12 // 1 byte: Soak time between increments (minutes)
#define EEPROM_CAL_DRY_ADDR         13   // 2 bytes: Sensor dry ADC value
#define EEPROM_CAL_WET_ADDR         15   // 2 bytes: Sensor wet ADC value
#define EEPROM_PUMP_RATE_ADDR       17   // 4 bytes: Pump rate (mL/s as float)
#define EEPROM_BACKLIGHT_TIMEOUT_ADDR   21  // 2 bytes: Backlight timeout (minutes)
#define EEPROM_SENSOR_WARMUP_ADDR      23  // 2 bytes: Sensor warmup (milliseconds)
#define EEPROM_NUM_MEASUREMENTS_ADDR   25  // 1 byte: Number of measurements (5-50)
#define EEPROM_MEASUREMENT_DELAY_ADDR  26  // 2 bytes: Delay between measurements (ms)
#define EEPROM_LOG_INTERVAL_ADDR       28  // 2 bytes: Log interval (minutes)
#define EEPROM_WRITE_PTR_ADDR          30  // 4 bytes: Circular buffer write pointer
#define EEPROM_TOTAL_ENTRIES_ADDR      34  // 4 bytes: Total entries written
#define EEPROM_WATERING_ENABLED_ADDR   38  // 1 byte: Auto-watering enabled (0=off, 1=on)

// Data section (40-1023: circular buffer for log entries)
#define EEPROM_DATA_START_ADDR      40
#define EEPROM_DATA_END_ADDR        1023
#define EEPROM_DATA_SIZE            984
#define ENTRY_SIZE                  4
#define MAX_ENTRIES                 246  // 984 / 4

#define EEPROM_MAGIC_NUMBER         0xA5C3

// Entry flags
#define FLAG_NORMAL                 0x00
#define FLAG_WATERING_STARTED       0x01
#define FLAG_WATERING_COMPLETE      0x02

// ============================================================================
// CONFIGURATION STRUCTURE
// ============================================================================

struct Config {
    // Watering parameters
    uint8_t targetHumidity;         // Target moisture % (0-100) - stop watering
    uint8_t minThreshold;           // Minimum threshold for dry cycle (0-100) - start watering
    uint16_t waterAmountInitial;    // Initial water amount in mL × 10 (for 0.1 mL precision)
    uint16_t waterAmountIncrement;  // Increment water amount in mL × 10 (for each iteration)
    uint8_t checkInterval;          // Check interval in hours (1-24)
    uint8_t soakTime;               // Soak time after initial pump in minutes (1-30)
    uint8_t soakTimeIncrement;      // Soak time between increments in minutes (1-30)

    // Sensor parameters
    uint16_t sensorDry;             // ADC value when sensor is in air (14-bit: 0-16383)
    uint16_t sensorWet;             // ADC value when sensor in water @ 60cm (14-bit: 0-16383)
    float pumpRate;                 // Pump flow rate in mL/s

    // Display parameters
    uint16_t backlightTimeout;      // Backlight timeout (minutes, 1-60)
    uint16_t sensorWarmup;          // Sensor warmup delay (milliseconds, 100-2000)
    uint8_t numMeasurements;        // Number of samples for median (5-50)
    uint16_t measurementDelay;      // Delay between samples (milliseconds, 10-500)
    uint16_t logInterval;           // Log interval in minutes (1-60)
    uint8_t wateringEnabled;        // Auto-watering active (1=on, 0=off)
};

// Default configuration
Config config = {
    .targetHumidity = 75,           // Target 75% (upper limit - stop watering)
    .minThreshold = 55,             // Water when below 55% (lower limit - start watering)
    .waterAmountInitial = 500,      // 50.0 mL initial watering (stored as 500 = 50.0 * 10)
    .waterAmountIncrement = 100,    // 10.0 mL per increment (stored as 100 = 10.0 * 10)
    .checkInterval = 6,             // Check every 6 hours (during dry cycle)
    .soakTime = 15,                 // Wait 15 minutes after initial pump for moisture propagation
    .soakTimeIncrement = 1,         // Wait 1 minute between increments for moisture propagation
    .sensorDry = 11850,             // Typical 14-bit ADC value in air (user-calibrated)
    .sensorWet = 7700,              // 14-bit ADC value in water @ 60cm
    .pumpRate = 1.67,               // Typical peristaltic pump ~100mL/min = 1.67mL/s
    .backlightTimeout = 1,          // 1 minute LCD sleep
    .sensorWarmup = 1000,           // 1000ms warmup time
    .numMeasurements = 10,          // 10 samples for median
    .measurementDelay = 100,        // 100ms between samples
    .logInterval = 15,              // Log every 15 minutes
    .wateringEnabled = 1            // Auto-watering enabled by default
};

// ============================================================================
// LOG ENTRY STRUCTURE
// ============================================================================

struct LogEntry {
    uint8_t moisturePercent;        // 0-100%
    uint16_t rawADC;                // Median ADC value (14-bit: 0-16383)
    uint8_t flags;                  // Status flags (watering events)
};

// ============================================================================
// MENU STATE MACHINE
// ============================================================================

enum MenuState {
    STATUS_SCREEN,                  // Default: Live moisture display
    MAIN_MENU,                      // Menu selection
    SETTINGS_MENU,                  // Settings submenu
    SETTING_TARGET,                 // Adjust target humidity
    SETTING_MIN,                    // Adjust min threshold
    SETTING_AMOUNT_INITIAL,         // Adjust initial water amount
    SETTING_AMOUNT_INCREMENT,       // Adjust increment water amount
    SETTING_INTERVAL,               // Adjust check interval
    SETTING_SOAK_TIME,              // Adjust soak time after initial
    SETTING_SOAK_TIME_INCREMENT,    // Adjust soak time between increments
    SETTING_LOG_INTERVAL,           // Adjust log interval
    SETTING_SENSOR_WARMUP,          // Adjust sensor warmup
    SETTING_NUM_MEASUREMENTS,       // Adjust num samples
    SETTING_MEASUREMENT_DELAY,      // Adjust measurement delay
    SETTING_BACKLIGHT_TIMEOUT,      // Adjust LCD sleep timeout
    CALIBRATE_MENU,                 // Calibration submenu
    CAL_SENSOR_MENU,                // Sensor calibration submenu
    CAL_SENSOR_AIR,                 // Measure dry value (in air)
    CAL_SENSOR_WATER,               // Measure wet value (in water)
    CAL_SENSOR_DONE,                // Measurement complete
    CAL_PUMP_START,                 // Pump calibration start
    CAL_PUMP_RUNNING,               // Pump running
    CAL_PUMP_ENTER_ML,              // Enter measured mL
    CAL_PUMP_DONE,                  // Pump calibration done
    MANUAL_WATER_CONFIRM,           // Confirm manual watering
    MANUAL_WATER_RUNNING,           // Manual watering in progress
    DOWNLOAD_MENU,                  // Download data menu
    DOWNLOAD_CONFIRM,               // Confirm download
    DOWNLOAD_PROGRESS,              // Downloading...
    RESET_CONFIRM                   // Confirm reset to defaults
};

MenuState currentState = STATUS_SCREEN;
uint8_t menuIndex = 0;              // Current menu selection
uint8_t settingsIndex = 0;          // Settings menu item index
uint8_t calibrateIndex = 0;         // Calibrate menu item index

// ============================================================================
// GLOBAL VARIABLES
// ============================================================================

int currentMoisture = 0;            // Current moisture reading (%)
uint16_t currentRawADC = 0;         // Current raw ADC value
unsigned long lastCheckTime = 0;    // Last moisture check timestamp (unused, kept for compatibility)
unsigned long lastWateringTime = 0; // Last watering timestamp
unsigned long lastLogTime = 0;      // Last data log timestamp
uint8_t dryReadingCount = 0;        // Consecutive below-threshold readings (debounce counter)
unsigned long lastDisplayUpdate = 0; // Last display update timestamp
bool backlightOn = true;            // LCD backlight state
unsigned long lastActivity = 0;     // Last user activity timestamp

// Calibration temporary variables
uint16_t tempSensorDry = 0;
uint16_t tempSensorWet = 0;
unsigned long pumpCalibrationStart = 0;
uint16_t pumpCalibrationML = 0;

// Button debouncing
unsigned long lastButtonPress = 0;
#define DEBOUNCE_DELAY 200          // 200ms debounce

// Display update interval
#define DISPLAY_UPDATE_INTERVAL 2000 // 2 seconds

// ============================================================================
// SETUP
// ============================================================================

void setup() {
    // Initialize serial for debugging and CSV download
    Serial.begin(115200);
    Serial.print(F("Plant Watering System v"));
    Serial.println(F(VERSION_STRING));

    // Configure ADC for 14-bit resolution (0-16383)
    // CRITICAL: Without this, Arduino defaults to 10-bit (0-1023)
    analogReadResolution(14);

    // Initialize pins
    pinMode(SENSOR_DISABLE_PIN, OUTPUT);
    pinMode(PUMP_PIN, OUTPUT);
    pinMode(BTN_UP, INPUT_PULLUP);
    pinMode(BTN_DOWN, INPUT_PULLUP);
    pinMode(BTN_SELECT, INPUT_PULLUP);
    pinMode(BTN_BACK, INPUT_PULLUP);

    // Ensure pump is off and sensor is disabled
    digitalWrite(PUMP_PIN, LOW);
    digitalWrite(SENSOR_DISABLE_PIN, HIGH);  // HIGH = disabled (low-power mode)

    // Initialize LCD
    lcd.init();
    lcd.backlight();
    lcd.clear();
    lcd.setCursor(0, 0);
    lcd.print(F("Plant Watering"));
    lcd.setCursor(0, 1);
    lcd.print(F("v"));
    lcd.print(F(VERSION_STRING));
    delay(2000);

    // Load configuration from EEPROM
    loadConfig();

    // Take initial moisture reading
    currentMoisture = readMoisture();

    // Display status screen
    displayMenu();

    Serial.println(F("Setup complete"));
}

// ============================================================================
// MAIN LOOP
// ============================================================================

void loop() {
    unsigned long currentTime = millis();

    // Handle button input (always responsive)
    handleButtons();

    // Update display if on status screen AND backlight is on
    if (currentState == STATUS_SCREEN && backlightOn &&
        currentTime - lastDisplayUpdate >= DISPLAY_UPDATE_INTERVAL) {
        currentMoisture = readMoisture();
        displayMenu();
        lastDisplayUpdate = millis();
    }

    // Check moisture + auto-water at every logInterval (only on status/menu screens)
    if (currentState == STATUS_SCREEN || currentState == MAIN_MENU) {
        unsigned long logIntervalMs = (unsigned long)config.logInterval * 60000UL;
        if (currentTime - lastLogTime >= logIntervalMs) {
            lastLogTime = currentTime;
            currentMoisture = readMoisture();
            logMoistureReading(FLAG_NORMAL);

            if (config.wateringEnabled) {
                if (currentMoisture <= (int)config.minThreshold) {
                    dryReadingCount++;
                    if (dryReadingCount >= 2) {
                        waterPlant();
                        logMoistureReading(FLAG_WATERING_COMPLETE);
                        dryReadingCount = 0;
                    }
                } else {
                    dryReadingCount = 0;
                }
            }
        }
    }

    // Update backlight (auto-sleep)
    updateBacklight();

    delay(50);  // Small delay to reduce CPU usage
}

// ============================================================================
// SENSOR READING
// ============================================================================

int readMoisture() {
    // Enable sensor (DIS LOW = active)
    digitalWrite(SENSOR_DISABLE_PIN, LOW);
    delay(config.sensorWarmup);

    // Allocate sample array
    int* samples = new int[config.numMeasurements];
    int minADC = 16383;
    int maxADC = 0;

    // Collect samples
    for (int i = 0; i < config.numMeasurements; i++) {
        int reading = analogRead(SENSOR_ADC_PIN);
        samples[i] = reading;

        if (reading < minADC) minADC = reading;
        if (reading > maxADC) maxADC = reading;

        if (i < config.numMeasurements - 1) {
            delay(config.measurementDelay);
        }
    }

    // Sort for median (bubble sort)
    for (int i = 0; i < config.numMeasurements - 1; i++) {
        for (int j = 0; j < config.numMeasurements - i - 1; j++) {
            if (samples[j] > samples[j + 1]) {
                int temp = samples[j];
                samples[j] = samples[j + 1];
                samples[j + 1] = temp;
            }
        }
    }

    // Calculate median
    int medianReading;
    if (config.numMeasurements % 2 == 0) {
        int mid = config.numMeasurements / 2;
        medianReading = (samples[mid - 1] + samples[mid]) / 2;
    } else {
        medianReading = samples[config.numMeasurements / 2];
    }

    delete[] samples;

    currentRawADC = medianReading;
    digitalWrite(SENSOR_DISABLE_PIN, HIGH);  // Disable sensor (DIS HIGH = sleep)

    // Convert to percentage using calibration values
    int moisturePercent = map(medianReading, config.sensorDry, config.sensorWet, 0, 100);
    moisturePercent = constrain(moisturePercent, 0, 100);

    Serial.print(F("ADC: "));
    Serial.print(medianReading);
    Serial.print(F(" ("));
    Serial.print(minADC);
    Serial.print(F("-"));
    Serial.print(maxADC);
    Serial.print(F(") -> "));
    Serial.print(moisturePercent);
    Serial.println(F("%"));

    return moisturePercent;
}

int readMoistureRaw() {
    // Read raw ADC value (for calibration)
    digitalWrite(SENSOR_DISABLE_PIN, LOW);
    delay(config.sensorWarmup);

    int* samples = new int[config.numMeasurements];

    for (int i = 0; i < config.numMeasurements; i++) {
        samples[i] = analogRead(SENSOR_ADC_PIN);
        if (i < config.numMeasurements - 1) {
            delay(config.measurementDelay);
        }
    }

    // Sort for median
    for (int i = 0; i < config.numMeasurements - 1; i++) {
        for (int j = 0; j < config.numMeasurements - i - 1; j++) {
            if (samples[j] > samples[j + 1]) {
                int temp = samples[j];
                samples[j] = samples[j + 1];
                samples[j + 1] = temp;
            }
        }
    }

    int median;
    if (config.numMeasurements % 2 == 0) {
        int mid = config.numMeasurements / 2;
        median = (samples[mid - 1] + samples[mid]) / 2;
    } else {
        median = samples[config.numMeasurements / 2];
    }

    delete[] samples;
    digitalWrite(SENSOR_DISABLE_PIN, HIGH);

    return median;
}

// ============================================================================
// WATERING LOGIC
// ============================================================================

bool shouldWater() {
    // Dry cycle logic: only water if at or below minimum threshold
    return currentMoisture <= config.minThreshold;
}

void waterPlant() {
    Serial.println(F("Starting watering cycle..."));

    int initialMoisture = currentMoisture;
    int iterationCount = 0;
    const int maxIterations = 20;  // Safety limit

    // PHASE 1: Initial pump
    {
        Serial.println(F("Phase 1: Initial pump"));
        float amountML = config.waterAmountInitial / 10.0;
        pumpWater(amountML);

        // Wait for moisture to propagate
        Serial.print(F("Waiting "));
        Serial.print(config.soakTime);
        Serial.println(F(" minutes for moisture propagation..."));

        unsigned long soakTimeMs = (unsigned long)config.soakTime * 60000UL;
        unsigned long soakStart = millis();
        while (millis() - soakStart < soakTimeMs) {
            currentMoisture = readMoisture();
            lcd.clear();
            lcd.setCursor(0, 0);
            lcd.print(F("Soaking  "));
            lcd.print(currentMoisture);
            lcd.print(F("%"));
            lcd.setCursor(0, 1);
            unsigned long remaining = (soakTimeMs - (millis() - soakStart)) / 1000;
            lcd.print(remaining);
            lcd.print(F("s left"));
        }

        initialMoisture = currentMoisture;
    }

    // PHASE 2: Incremental pump until target reached
    while (currentMoisture < config.targetHumidity && iterationCount < maxIterations) {
        iterationCount++;

        Serial.print(F("Phase 2: Increment "));
        Serial.println(iterationCount);

        // Pump increment amount (mL)
        float amountML = config.waterAmountIncrement / 10.0;
        pumpWater(amountML);

        // Wait for moisture to propagate
        Serial.print(F("Waiting "));
        Serial.print(config.soakTimeIncrement);
        Serial.println(F(" minutes for moisture propagation..."));

        // Display watering status during soak time
        unsigned long soakTimeMs = (unsigned long)config.soakTimeIncrement * 60000UL;
        unsigned long soakStart = millis();
        while (millis() - soakStart < soakTimeMs) {
            currentMoisture = readMoisture();
            lcd.clear();
            lcd.setCursor(0, 0);
            lcd.print(F("Soaking  "));
            lcd.print(currentMoisture);
            lcd.print(F("%"));
            lcd.setCursor(0, 1);
            unsigned long remaining = (soakTimeMs - (millis() - soakStart)) / 1000;
            lcd.print(remaining);
            lcd.print(F("s left"));
        }

        // Failsafe: if moisture didn't increase, stop watering
        if (currentMoisture <= initialMoisture) {
            Serial.println(F("ERROR: Moisture not increasing - stopping!"));
            lcd.clear();
            lcd.setCursor(0, 0);
            lcd.print(F("ERROR!"));
            lcd.setCursor(0, 1);
            lcd.print(F("Check sensor/pump"));
            delay(5000);
            break;
        }

        initialMoisture = currentMoisture;
    }

    if (iterationCount >= maxIterations) {
        Serial.println(F("WARNING: Max watering iterations reached"));
    }

    Serial.println(F("Watering cycle complete"));
    lastWateringTime = millis();
}
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

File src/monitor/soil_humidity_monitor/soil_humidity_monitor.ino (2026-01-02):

/*
 * Soil Humidity Monitor - Monitoring Variant
 *
 * Hardware: Arduino UNO R4 WiFi
 * Display: 16x2 I2C LCD
 *
 * Features:
 * - Continuous soil moisture monitoring
 * - EEPROM circular buffer logging (14 days @ 15-min intervals)
 * - CSV data download via Serial (115200 baud)
 * - Sensor calibration wizard
 * - User-adjustable log interval (1-60 minutes)
 * - GPIO-powered sensor (extends lifespan)
 * - No watering functionality (monitoring only)
 *
 * Pin Assignments:
 * - A0: Soil Moisture Sensor (ADC)
 * - D2: Sensor Power Control
 * - D3: UNUSED (pump pin in POC)
 * - SDA (A4): LCD SDA
 * - SCL (A5): LCD SCL
 * - D4: Button UP
 * - D5: Button DOWN
 * - D6: Button SELECT
 * - D7: Button BACK
 * - D10-D13: UNUSED (SD card in POC)
 */

#include <Wire.h>
#include <LiquidCrystal_I2C.h>
#include <EEPROM.h>

// ============================================================================
// PIN DEFINITIONS
// ============================================================================

#define SENSOR_ADC_PIN      A0    // Soil moisture sensor analog input
#define SENSOR_POWER_PIN    2     // GPIO power control for sensor
#define BTN_UP              4     // Navigation button: UP
#define BTN_DOWN            5     // Navigation button: DOWN
#define BTN_SELECT          6     // Navigation button: SELECT
#define BTN_BACK            7     // Navigation button: BACK

// ============================================================================
// LCD CONFIGURATION
// ============================================================================

// Try 0x27 first, if that doesn't work try 0x3F
LiquidCrystal_I2C lcd(0x27, 16, 2);

// ============================================================================
// EEPROM MEMORY MAP
// ============================================================================

// Header section (32 bytes: 0-31)
#define EEPROM_MAGIC_ADDR           0    // 2 bytes: Magic number (0xA5C3)
#define EEPROM_VERSION_ADDR         2    // 2 bytes: Firmware version
#define EEPROM_LOG_INTERVAL_ADDR    4    // 2 bytes: Log interval (minutes)
#define EEPROM_CAL_DRY_ADDR         6    // 2 bytes: Sensor dry ADC value
#define EEPROM_CAL_WET_ADDR         8    // 2 bytes: Sensor wet ADC value
#define EEPROM_WRITE_PTR_ADDR       10   // 4 bytes: Circular buffer write pointer
#define EEPROM_TOTAL_ENTRIES_ADDR   14   // 4 bytes: Total entries written
#define EEPROM_FIRST_TS_ADDR        18   // 2 bytes: First entry timestamp (hours)
#define EEPROM_FLAGS_ADDR           20   // 1 byte: Buffer flags
#define EEPROM_HEADER_CHECKSUM_ADDR 31   // 1 byte: Header checksum

// Data section (32-5407: 5376 bytes = 1344 entries × 4 bytes)
#define EEPROM_DATA_START_ADDR      32
#define EEPROM_DATA_END_ADDR        5407
#define EEPROM_DATA_SIZE            5376
#define ENTRY_SIZE                  4
#define MAX_ENTRIES                 1344

#define EEPROM_MAGIC_NUMBER         0xA5C3
#define FIRMWARE_VERSION            0x0100  // v1.0

// Entry flags
#define FLAG_SENSOR_ERROR    0x10  // bit 4: Sensor error detected
#define FLAG_OUT_OF_RANGE    0x20  // bit 5: Reading out of range

// Buffer flags
#define FLAG_BUFFER_WRAPPED  0x01  // bit 0: Circular buffer has wrapped

// ============================================================================
// CONFIGURATION STRUCTURE
// ============================================================================

struct Config {
    uint16_t logInterval;       // Log interval in minutes (1-60)
    uint16_t sensorDry;         // ADC value when sensor is in air (14-bit: 0-16383)
    uint16_t sensorWet;         // ADC value when sensor is in water (14-bit: 0-16383)
    uint32_t writePointer;      // Current write position in circular buffer
    uint32_t totalEntries;      // Total entries written (lifetime)
    uint16_t firstTimestamp;    // Hours since boot for first entry
    uint8_t flags;              // Buffer status flags
};

// Default configuration
Config config = {
    .logInterval = 15,          // 15 minutes (exactly 14 days)
    .sensorDry = 12400,         // Typical 14-bit ADC value in air
    .sensorWet = 6000,          // Typical 14-bit ADC value in water
    .writePointer = 0,          // Start of buffer
    .totalEntries = 0,          // No entries yet
    .firstTimestamp = 0,        // 0 hours (boot time)
    .flags = 0                  // No flags set
};

// ============================================================================
// LOG ENTRY STRUCTURE
// ============================================================================

struct LogEntry {
    uint8_t moisturePercent;    // 0-100%
    uint16_t rawADC;            // 14-bit ADC value (0-16383)
    uint8_t flags;              // Status flags
};

// ============================================================================
// MENU STATE MACHINE
// ============================================================================

enum MenuState {
    STATUS_SCREEN,          // Default: Live moisture display
    MAIN_MENU,             // Menu selection
    SETTINGS_MENU,         // Settings submenu
    SETTING_LOG_INTERVAL,  // Adjust log interval
    CALIBRATE_MENU,        // Calibration submenu
    CAL_SENSOR_START,      // Sensor calibration start
    CAL_SENSOR_AIR,        // Read dry value
    CAL_SENSOR_WATER,      // Read wet value
    CAL_SENSOR_DONE,       // Calibration complete
    DOWNLOAD_MENU,         // Download data menu
    DOWNLOAD_CONFIRM,      // Confirm download
    DOWNLOAD_PROGRESS,     // Downloading...
    DOWNLOAD_COMPLETE,     // Download done
    CLEAR_DATA_CONFIRM,    // Confirm clear data
    SYSTEM_INFO,           // System information
    RESET_CONFIRM          // Confirm reset to defaults
};

MenuState currentState = STATUS_SCREEN;
uint8_t menuIndex = 0;           // Current menu selection
uint8_t settingsIndex = 0;       // Settings menu item index
uint8_t calibrateIndex = 0;      // Calibrate menu item index

// ============================================================================
// GLOBAL VARIABLES
// ============================================================================

int currentMoisture = 0;         // Current moisture reading (%)
unsigned long lastLogTime = 0;   // Last data log timestamp
unsigned long lastDisplayUpdate = 0; // Last display update timestamp
bool backlightOn = true;         // LCD backlight state
unsigned long lastActivity = 0;  // Last user activity timestamp

// Calibration temporary variables
uint16_t tempSensorDry = 0;
uint16_t tempSensorWet = 0;

// Button debouncing
unsigned long lastButtonPress = 0;
#define DEBOUNCE_DELAY 200       // 200ms debounce

// Display update intervals
#define DISPLAY_UPDATE_INTERVAL 2000    // 2 seconds
#define BACKLIGHT_TIMEOUT 60000         // 1 minute

// ============================================================================
// SETUP
// ============================================================================
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

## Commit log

2026-01-01 monitor only functionality
    [monitor.kicad_pcb, monitor.kicad_sch, soil_humidity_monitor.kicad_sch]
2026-01-02 monitor functionality v1.0
    [monitor.kicad_sch]
2026-01-02 Monitor v1.1: Live ADC display, manual calibration, and project restructuring
    ## Monitor Variant v1.1 Features
    - Live ADC value display on status screen (M:XX% ADC:XXXXX)
    - Real-time calibration feedback (ADC updates every 0.5s during wizard)
    - Manual calibration value editing (±1 increments for fine-tuning)
    - Enhanced System Info menu showing calibration values and settings
    - Centralized version information in firmware constants
    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
    [monitor.kicad_pcb, monitor.kicad_sch, soil_humidity_monitor.kicad_sch]
2026-01-02 folder refactor is a need for arduino ide
2026-01-02 Sensor reading stability
2026-01-02 Monitor v1.1 hotfix: ADC resolution and flexible calibration
    Critical fixes and UX improvements for soil humidity monitor:
    - Fix ADC resolution configuration (14-bit mode required for UNO R4)
    * Add analogReadResolution(14) in setup() - was reading 10-bit by default
    * Resolves calibration values 16x too low (e.g., 560 instead of 12,400)
    * Users must re-upload firmware and recalibrate sensor
    - Refactor calibration menu for independent dry/wet calibration
    * Separate Dry Value and Wet Value submenus
    * Each has "Measure Now" (automatic) and "Edit Manually" options
    * No longer forced to calibrate both in sequence
    * Manual edit: ±50 step size with auto-rounding to multiples of 50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
    [soil_humidity_monitor.ino]
2026-01-03 Monitor v1.2-v1.4: Configurable parameters, memory optimization, and DIS pin control
    This commit includes three unreleased versions (v1.2, v1.3, v1.4):
    v1.2: Configurable sensor parameters
    - Add Settings menu for backlight timeout, sensor warmup, num measurements, delay
    - Add min/max ADC tracking in CSV export
    - Entry size: 4 → 8 bytes, capacity: 1,344 → 672 entries
    v1.3: Memory optimization
    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
    [monitor.kicad_sch]
2026-03-01 Project cleanup: watering firmware only
    - Remove monitor firmware, KiCad PCB, docs/, src/ POC, and superseded docs
    - Rename BOM_POC.md → BOM.md
    - Rewrite README with schematic, badges, and design decisions table
    - Update MENU_DESIGN.md to match v1.1 firmware (defaults, state machine, EEPROM map)
    - Condense LESSONS_DEEP_RESEARCH.md by ~50%
    - Add LICENSE (MIT)
    [monitor.kicad_pcb, monitor.kicad_sch, soil_humidity_monitor.kicad_sch]
2026-10-11 Reorganize project for the 6-plant ESP32-S3 system
    - Move KiCad to hardware/kicad and rename the project to plant_watering
    - Remove the old single-plant KiCad files and Arduino sketches
    - Add PlatformIO project, PlantLogic library, OLED menu firmware and tests
    - Add BOM derived from the schematic, archive Arduino-era docs
    - README: new overview, pin map and TODO list
2026-10-12 Mount UI module on the PCB, panel USB-C input, extra mounting holes
    - J2: replace the JST-XH 9-pin with a 1x9 2.54 mm socket plus the UI
    module's four M3 standoff holes (new UI_module_OLED_EC11 footprint);
    the module plugs in face-up left of the ESP32 and screws down
    - Board widened to 143 x 112 mm for the module; UI nets rerouted,
    corner holes moved, three extra M3 holes beside J3-J8 against flex
    - J1: JST-PH 6-pin for a panel-mount USB-C socket cable
    - MT3608 footprint updated to measured hole spacing (26 x 13 mm)
    - README/BOM: UI module photo and mounting notes, ESP pinout and
    IN-OUT jumper warning, 1:1 printable board PDF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
2026-10-12 Add 3D models for the ESP32, UI and MT3608 modules
    Simplified coloured STEP models generated by small pure-Python scripts
    (shared step_writer.py, boxes and cylinders) in plant_watering_parts.3dshapes,
    referenced from the project footprints and the board via ${KIPRJMOD}.
2026-10-12 Update board render with the module 3D models
2026-10-12 Simplify USB-C power input to a 2-pin V+/V- connector
    J1 becomes a JST-XH 2-pin header (1 GND, 2 +5V) for a 2-wire panel
    USB-C socket. Drop the CC pull-downs R13/R14 and the CC1/CC2 nets; the
    socket must provide its own 5.1k CC resistors for C-to-C chargers.
    Update BOM, README and the 3D view image.
2026-10-12 Add fabrication export script and manufacturing guide
    hardware/fab/export_fab.py exports Gerbers + Excellon drills from a temp
    copy of the board (DRC-checked): a standard zip (finished hole sizes, for
    PCBWay/JLCPCB) and a prototypy.com zip with plated pad holes +0.1 mm.
    docs/MANUFACTURING.md documents the order settings, hole sizes per maker
    and design limits.
2026-10-12 Prepare prototypy.com fab files per their instructions
    - Round enlarged plated holes up to drills prototypy.com stocks (1.05 -> 1.1)
    and check their pad >= hole + 0.44 mm rule
    - Plain RS-274X Gerbers (no X2, no aperture macros), Excellon in inches,
    decimal, plus a drill report as the tools file
    - Document their requirements vs. what we send, and a Polish order comment
    - Keep their KiCad export guide (2007 PDF) for reference
2026-10-12 Manufacturing doc: 1.5 mm at prototypy.com, shorter order comment
    The Polish order comment now only covers the deviations from their
    instructions (metric Gerbers, separate PTH/NPTH drill files).
2026-10-13 Add board title and goat logo to silkscreen; drop prototypy.com export
    - Top-left silkscreen: goat logo (source in hardware/kicad/goat_logo.svg)
    and "Another watering system v0.1"
    - export_fab.py now writes only the standard Gerber zip; removed the
    prototypy.com zip, their KiCad guide PDF and the related docs
    - Regenerated plant_watering-gerbers.zip
2026-10-13 Billy goat logo on the PCB, head logo and colour illustration
    - Silkscreen goat is now a billy goat (tapering pointed horn, long beard,
    no chest tuft); Gerbers regenerated, DRC clean
    - goat_head_logo.svg: detailed front-view head for KiCad import, built
    as hole-free polygons by goat_head_logo.py (shapely)
    - docs/goat_mountain.png: colour illustration of the goat on a mountain
2026-10-17 Add open test rig for the PCB and six pumps
    case/test_rig.py (build123d) generates a one-piece printed tray: the PCB
    on five posts with heat-set inserts, the pump motors running underneath
    it, two pumps on each side wall and two on the back wall so the display
    end stays clear. Motors drop into open-top U slots and hang on M3 rubber
    anti-vibration mounts, with foam pads under their free ends. The script
    reads the mounting holes from the KiCad board, checks the rig and both
    pump mountings against every board part, and writes case/print/.
    README: printing, hardware and assembly instructions for the rig.
    Pump drawing added under docs/ as the source of the pump model.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
